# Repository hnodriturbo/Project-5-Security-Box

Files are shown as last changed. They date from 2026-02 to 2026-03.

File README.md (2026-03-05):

# Project 5 – 3D Printed Security Drawer Box

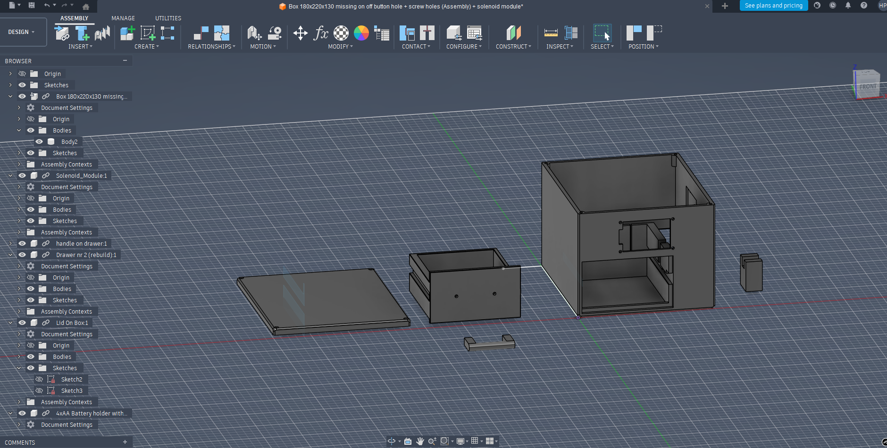
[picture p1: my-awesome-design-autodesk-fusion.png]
Fusion Design


---

## Latest update = VIDEO USAGE:

https://github.com/hnodriturbo/Project-5-Security-Box/raw/master/usage_function_video.mp4

NOTE: MAIN CODE IS IN /esp32-s3

---
## 1. Project Overview

3D printed IoT security drawer box built around an ESP32-S3 and Raspberry Pi running NiceGUI.

### Unlock Methods
- RFID authentication  
- Remote MQTT unlock from dashboard  

The system validates real physical drawer movement using a reed switch and reports whether the unlock was confirmed or failed.

This project demonstrates:

- IoT communication using MQTT  
- JSON-based data exchange  
- Real actuator control (solenoid)  
- Physical validation using reed switch  
- Mechanical precision 3D design  

---

## 2. System Architecture

ESP32 ↔ MQTT Broker ↔ Raspberry Pi (NiceGUI)

### ESP32
- Handles RFID authentication  
- Controls solenoid via TB6612FNG  
- Reads reed switch state  
- Drives OLED display  
- Controls LED strip  
- Sends heartbeat and status data  

### Raspberry Pi
- Hosts NiceGUI dashboard  
- Sends remote unlock command  
- Displays system status  
- Logs events  

---

## 3. Flow Chart

<p align="center">
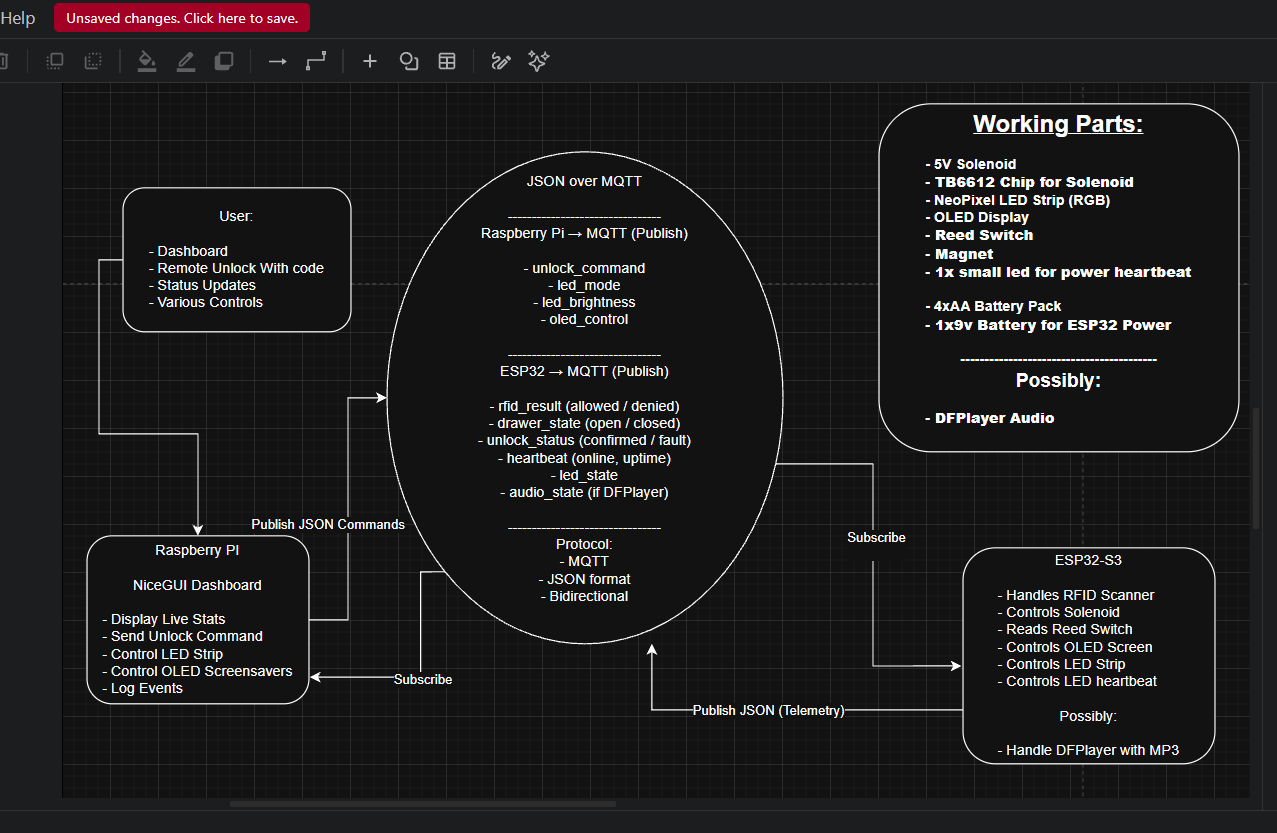
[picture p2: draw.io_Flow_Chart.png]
  
</p>

The system flow chart was created in draw.io and illustrates:

- Authentication logic  
- Unlock decision flow  
- Reed confirmation  
- Fault handling  
- Reset logic  

---

## 4. Hardware

- ESP32-S3  
- TB6612FNG motor driver  
- 5V solenoid lock  
- Reed switch + magnet  
- MFRC522 RFID reader  
- 2.42" OLED (SSD1309 SPI)  
- NeoPixel LED strip (GRB)  
- 9V battery (logic power)  
- 4xAA battery pack (solenoid power)  
- Raspberry Pi  

---

## 5. MQTT & IoT Protocol

Communication protocol used:

- MQTT  
- JSON  

Broker will be used using mosquitto and Raspberry Pi system using the school network
- Known broker IP: `10.201.48.7` (could be something else next time it powers on)

All communication between ESP32 and Raspberry Pi is handled using structured JSON messages over MQTT.

Detailed message formats will be documented separately in the project documentation.

---

## 6. Software

### ESP32

Programmed in **MicroPython**.  
Handles hardware interaction, MQTT communication, state management, and feedback systems.

### Raspberry Pi

Runs **NiceGUI (Python)**.  
Provides dashboard interface, remote control functionality, and live monitoring.

---

## 7. CAD & Mechanical Design

Folder: `cad/`

Designed in Autodesk Fusion.

Contains STL exports for:

- **Main Box Design**
- **Sliding Drawer Design**
- **Sliding Drawer Handle Design**
- **Solenoid Mounting Structure Design**
- **Spring Holders Design**

The design focuses heavily on mechanical precision due to the solenoid having approximately 2mm of usable locking depth.

---

## 8. Known Limitations

- Battery powered demo build  
- High LED + solenoid load may cause voltage drop  
- Mechanical tolerances will be fully validated after final print  

---

## 9. Future Improvements

- DFPlayer Mini + speaker for audio feedback  
- Internal voltage regulation  
- Improved drawer alignment refinement ✅ 
- Local MQTT broker on Raspberry Pi ✅ 

---

## 10. Project Coverage

This project fulfills:

- Telemetry  
- Actuator control  
- Raspberry Pi + NiceGUI integration  
- Full IoT physical prototype design  
- 3D printed mechanical system

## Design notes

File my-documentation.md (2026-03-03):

# Documentation of Creation of the Security Box

This document logs the development process of the 3D Printed IoT Security Drawer Box.  
It describes design decisions, challenges, mechanical iterations, and open questions during development.

---

## 15–22 Feb — Mechanical Design Phase (Autodesk Fusion)

During this period I focused heavily on the mechanical design of the box in Autodesk Fusion.  
This phase required significant precision because the solenoid locking mechanism only has approximately **2mm of usable locking pin depth**, which leaves very little room for error.

--- 

## 26 Feb - Box printing failed, but drawer and solenoid stand + handle on drawer printed

I will have the box late or on Monday, 2 days before assignment completion so i have started working on the codings, having everything connected together at home illustrating the box design. This is a complex coding system that I'm designing so for ease of commanding everything I created a class file for every component that will be used, so instances can call easily on premade functions within those instance related classes.

PROBLEM: I thought the pin would have more power but 4xAA is not giving the pin the power to pull in when pressure is on it. Even just a tiny bit of pressure so the spring system will be withdrawed from the design and unlocking will unlock for 5 seconds and user has to manually open the drawer but otherwise it's locked into place by the solenoid. I would need more power then 4xAA batteries for making the pin pull in with force or this is just so basic and small solenoid that I must redesign this. It was not the main purpose but I will have to acumulate to these conditions and create new TRUE PURPOSE of the box by having the user having to open the drawer manually when presented with phone, card, keychain or command from dashboard. I will focus more on the engine design, the lightings and more to make up for this and create fully functional dashboard with NiceGUI that can make many different commands to the box, change screen main texts, change lighting scenes, unlock with a code (code only unlock from dashboard for "security") and more features will also be available in the dashboard.

---

## 27-28 Feb & 1-3 Mar — Printing Issues & Coding Phase

After the first full box print, I immediately ran into mechanical issues. The bottom surface of the box printed uneven, which affected structural alignment and drawer seating. Because of this, the drawer did not fit correctly. I had to manually adjust and widen certain areas using tools just to make it fit temporarily inside the faulty print. This obviously changed tolerances and is not acceptable for final assembly.

As a result:

- The full box is being reprinted and I am currently waiting for the new version.
- The drawer also needs to be reprinted to restore its true dimensions.
- These corrected parts will be ready tomorrow, on the day of the deadline.
- Final mechanical construction and full assembly will happen immediately once the prints are ready.

Because I did not want to lose time while waiting for the reprint, I shifted focus entirely to the coding phase.

---

## ESP32 Software Architecture Development

While waiting for the new box print, I built and structured the entire ESP32 system from scratch. This part was significantly more complex than expected.

The main difficulty was not hardware — it was architecture.

I wanted:

- Separate class files for every hardware component  
- Clean separation between logic, hardware, and MQTT communication  
- Two independent MQTT pathways (receive and transmit)  
- Structured JSON communication  
- No dynamic guessing or unsafe method calls  
- Beginner-readable but structured code  

This caused several major debugging cycles.

Problems I faced during development:

- MQTT client queue handling errors  
- Async task crashes not being retrieved properly  
- Reconnect loops failing silently  
- JSON parsing issues  
- Multiple overlapping log functions that needed to be merged  
- OLED display not updating because async calls were blocked  
- Unlock flow timers interfering with display logic  
- RFID scan loop not running due to incorrect task structure  
- ESP disconnecting after publish attempts  
- Attribute errors due to inconsistent broker methods  

The system had to be redesigned more than once to make it clean and understandable.

Eventually, I simplified everything into:

- A central `SecurityBoxController`  
- Explicit `CommandRouter`  
- One unified logging system  
- Minimal JSON messages  
- Two MQTT topics:  
  - Subscribe: `1404TOPIC/Commands`  
  - Publish: `1404TOPIC/Events`  
- Clear async task separation  
- Component classes that only do their own job  

After many iterations and structural changes, the ESP32 code is now stable and behaves as expected. HOPEFULLY!

---

## NiceGUI Dashboard & Broker Setup

While developing the ESP32 code, I also completed the NiceGUI dashboard.

I am using my own MQTT broker setup at home.  
Connection between:

ESP32 ↔ Broker ↔ NiceGUI

is working properly.

The dashboard can:

- Send unlock commands  
- Trigger LED effects  
- Change OLED screen text  
- Display structured events from the ESP  
- Log events with timestamps  
- Handle connection and reconnection states  

After a large number of debugging cycles and communication fixes, the full ESP ↔ MQTT ↔ NiceGUI communication loop is functioning correctly.

---

## Current Status Before Final Assembly

At this point:

- Solenoid works electrically - NOTE: SOMETIMES I NEED TO MOVE WIRES OR KNOCK ON THE SOLENOID FOR IT TO WORK - POSSIBLE HUGE PROBLEM !!!
- MQTT communication is verified  
- NiceGUI dashboard is fully operational  
- All component classes are structured and separated  
- LED strip effects and unlock flow logic completed  
  
- Reed switch should block everything that's going on and display on screen DRAWER OPEN until the magnet on the drawer connects the reed switch (then unlock the screen and loop)
- ESP32 code is stable except for reed sensor testing that is hard to do when not with the printed box and magnet glued on the drawer

Remaining steps:

- Receive corrected box and drawer print  
- Assemble full hardware  
- Mount electronics  
- Perform final mechanical alignment  
- Validate full unlock + drawer interaction  
- Record final test results  
  
Despite multiple mechanical and coding setbacks, the system is now logically complete and ready for final physical integration. (without reed sensor)

---

# Project information !!!

### CAD Tool Decision

I chose Autodesk Fusion because it provides:

- Parametric modeling
- Precise dimensional control
- Better constraint handling
- Timeline-based modification for iterative design

This project requires millimeter-level precision, especially around:
- Solenoid placement
- Drawer rail tolerances
- Reed switch alignment
- Magnet positioning

---

### Solenoid Mount Strategy

One important architectural decision was to design the solenoid stand as a **separate modular component** that will be glued into place.

Reasoning:

- If tolerances are slightly off after printing, I can reprint only the solenoid mount.
- Avoids reprinting the entire box structure.
- Allows micro-adjustments if the 2mm locking engagement needs repositioning
  
### Solenoid update 3.3.2026
- After positioning solenoid in the solenoid 3d printed stand it is exactly like it's supposed to be and fits perfectly even with its 1.7mm locking space inside the side of the drawer. Only check left is to see if it will open when springs on drawer will put light pressure on it (must have full battery power for stronger solenoid signal).
---

### Drawer & Internal Structure Challenges

Designing the internal structure took significantly more time than expected.

Key challenge:
Creating a space behind the inner drawer wall for:
- Springs
- Reed switch
- Magnet alignment

Final decision:
- **10mm gap** between drawer back wall and inner back wall.
- Magnet glued to rear of drawer.
- Reed switch mounted on internal wall.
- On closed position → magnet activates reed sensor.
- Solenoid engages locking pocket.

Because of spring pressure pushing the drawer forward, this entire system requires:
- Precise rail guidance
- Minimal side wobble
- Controlled alignment at locking point

To achieve this I:

- Increased wall thickness to **5mm standard**
- Added structural rails
- Designed inner reinforcement walls
- Added a mechanical stopper feature at the front so the drawer seats fully before rail alignment takes over

---

### Rail & Tolerance Adjustments

Several iterations were made regarding:

- Side clearances (0.3–0.6 mm precision clearences?)
- Vertical rail spacing
- Rail width (4mm → considered 5mm)
- Friction concerns with solenoid side-contact

Because the solenoid does not have a latch hook, friction against its body was a major design constraint.  
A slide geometry was introduced to gently push the solenoid inward ~1mm before it drops into the locking pocket.

The locking pocket itself was extended upward to allow manual widening with tools if necessary after printing.

---

### Front Panel & Electronics Mounting

Additional design work completed:

- Screw holes (4mm diameter, 10mm depth planned)
- Reinforced lid screw zones (extra material added)
- Inward extrudes for PCB mounting (OLED + RFID)
- Relief cut for OLED header pins
- Circular opening for RFID antenna to improve signal reliability

Special attention was given to:
- Avoiding stress concentration at corners
- Ensuring enough material thickness behind PCB mount areas
- Making sure drawer removal remains possible

---

### Power & Structural Considerations

Power design:
- 9V battery for ESP32 logic rail
- 4xAA battery pack for solenoid
- Shared ground

Concerns:
- Solenoid draws ~1A+
- LED strip can draw multiple amps at full white
- Risk of ESP brownout under heavy load

Structural reinforcement was added where necessary to reduce flex around locking area.

---

### Open Questions (To Be Answered After First Print)

The following mechanical uncertainties cannot be confirmed until physical testing:

- Will the 2mm solenoid locking depth reliably hold the drawer while springs push forward?

- When spring force is applied to the locking pin, will the solenoid release smoothly or bind due to lateral pressure?
  -  TRUE - Solenoid cannot open when even the slightest pressure is on it. I have no time to reprint new design to make the locking in a different way structurally. But would if i had more // 🕗 

- Will rail tolerances provide smooth sliding without wobble?

- Will the drawer self-align perfectly into the rails and locking pin lock the drawer?

- Will friction over time wear down the locking edge?
  - No it will not since this is only a part project that will be taken apart when finished.

These will only be confirmed during:
- First full assembly
- Solenoid activation testing
- MQTT + unlock validation phase

---

- Testing & Performance Results:
  - Testing the solenoid with all connected parts (not inside the box) seems good. Only problem is we need to exclude the springs because the solenoid will not open when friction is pushing on it by the springs pushing the drawer outwards.
  - SOLENOID DOESNT ALWAYS OPEN !!! NOTE: COULD BE FATAL TO PROJECT FUTURE AVAILABILITY BUT FOR NOW IT WORKS IN BETWEEN WHEN USING BRAND NEW BATTERIES.

---

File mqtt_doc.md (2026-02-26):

# MQTT Architecture Documentation  
Project 5 – 3D Printed Security Drawer Box  

---

# 1. Overview

This system uses a local MQTT broker running on the Raspberry Pi to connect:

- ESP32-S3 (MicroPython device inside the box)  
- NiceGUI dashboard (running on Raspberry Pi)  
- Mosquitto broker (running on Raspberry Pi)  

The broker acts as a message router between ESP32 and NiceGUI.

There is no direct communication between ESP32 and NiceGUI.  
All communication flows through MQTT.

---

# 2. System Architecture

## ESP32-S3

- RFID reader (MFRC522)  
- Reed switch (drawer state)  
- Solenoid (TB6612FNG driver)  
- OLED display  
- NeoPixel LED strip (GRB)  
- DFPlayer audio  
- MQTT client (MicroPython)

## Raspberry Pi

- Mosquitto MQTT Broker (port 1883)  
- NiceGUI Dashboard (Python application)  
- MQTT client inside NiceGUI  

---

# 3. Network Structure

## MQTT Broker

Runs locally on Raspberry Pi:

`Mosquitto`  
`Port: 1883`  
`Listener: 0.0.0.0`  
`Anonymous: true (demo mode)`

BROKER IP !!!!
`10.201.48.7`

## Connection Targets

| Device | Broker Address |
| --- | --- |
| NiceGUI  | `127.0.0.1` |
| ESP32-S3 | `10.201.48.77` |

---

# 4. Communication Flow

ESP32 publishes telemetry → Broker → NiceGUI receives  
NiceGUI publishes commands → Broker → ESP32 receives  

The broker is the central router.

---

# 5. Topic Structure

Base namespace:

`security_box/`

## 5.1 Telemetry (ESP32 → Pi)

`security_box/telemetry/heartbeat`  
`security_box/telemetry/drawer_state`  
`security_box/telemetry/system_status`

## 5.2 Events (ESP32 → Pi)

`security_box/event/rfid`  
`security_box/event/unlock_result`  
`security_box/event/fault`

## 5.3 Commands (Pi → ESP32)

`security_box/cmd/unlock`  
`security_box/cmd/led`   
`security_box/cmd/oled`

---

# 6. Unlock Flow Example

1. RFID scanned on ESP32  
2. ESP32 checks allowed UID  
3. If allowed:  
   - Activate solenoid  
   - Wait for reed switch change  
   - Publish `security_box/event/unlock_result`  
4. NiceGUI receives and logs result  

Remote unlock works similarly:

1. NiceGUI publishes to `security_box/cmd/unlock`  
2. ESP32 activates solenoid  
3. Reed switch validates open  
4. ESP32 publishes unlock result  

---

# 7. Summary

Raspberry Pi runs:

- Mosquitto (MQTT message router)  
- NiceGUI dashboard  

ESP32 runs:

- Hardware control logic  
- MQTT client  

All communication is JSON over MQTT using a structured namespace.

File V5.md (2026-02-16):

# Tímaverkefni 5 

- IoT frumgerð 
- Námsmat 32% af heildareinkunn  

---

## Verkefnalýsing

Lokaverkefnið snýr að IoT frumgerðasmíð. Viðfangefni og útfærsla er frjáls en er **háð samþykki kennara** og þarf að uppfylla ákveðna verkþætti (sjá neðar). Verkefnið þarf að vera ykkar eigið og gert er ráð fyrir **sjálfstæðum** vinnubrögðum. Skoðið [Adafruit](https://learn.adafruit.com/category/internet-of-things-iot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) og [Hackster](https://www.hackster.io/iot/projects) fyrir innblástur og hugmyndir. 

#### Verkþættir sem þarf að uppfylla:

- [ ] Telemetry: Unnið er með inntak frá völdum skynjurum, sjá [lista af íhlutum](https://github.com/VESM3/IOT/blob/main/Ihlutir.md).
- [ ] Actuators: Unnið er með valdar stýringar, sjá [lista af íhlutum](https://github.com/VESM3/IOT/blob/main/Ihlutir.md).
- [ ] MQTT Broker uppsetning, [leiðbeiningar](https://github.com/VESM3/IOT/blob/main/Efni/rpi_mqtt_nodered_uppsetning.md#mosquitto-mqtt-broker).
- [ ] NiceGUI: Mælaborði fyrir birtingu gagna og notendastýringar.
- [ ] IoT Protocol: MQTT. 
- [ ] JSON fyrir gögn.
- [ ] [Flæðirit](https://www.drawio.com/doc/getting-started-basic-flow-chart) (e. flow chart) af IoT Frumgerð.
- [ ] Samsettning á IoT búnaði (innfelld kerfi, íhlutir, brauðbretti, vírar osfrv.).
- [ ] Smíði IoT frumgerðar (3D prentað, 2D laserskornir, veróborðsmíði, lóðun, samsettning og útlit).
- [ ] Skýrsla á Github (readme.md).

---

### Skýrsla og skil

Búið til private Github geymslu (repository) og skrifið skýrslu ([leiðbeiningar](https://github.com/VESM1VS/AFANGI/blob/main/Kennsluefni/skyrslugerd.md)) í `readme.md` sem innheldur eftirfarandi: 

1. Stutt textalýsing á IoT frumgerð og virkni.
1. Stutt myndband af virkni. 
1. Ljósmyndir af IoT frumgerð.
1. Íhlutalisti, allir íhlutir sem notaðir eru í verkefninu.
1. Flæðirit (e. flow chart) af IoT Frumgerð.
1. Hönnunarteikningar (til prentunar) 2d (svg) og 3d teikningar (.stl skráin).
1. Tenglar á kóðaskrár vel commentað.

Skilið í Innu tengil á skýrsluna (`readme.md`). Skil á skýrslu er forsenda þess að gefin sé einkunn fyrir verkefnið. Hugið vel að uppsetningu og framsetningu! Vinsamlegast gerið einnig eftirfarandi í Innu: [Samþykki fyrir birtingu verkefnis á vef](https://github.com/VESM3/IOT/blob/main/Verkefni/samthykki.md) 

---

### Námsmat 

Einkunn byggir á útfærslum á eftirfarandi matsþáttum og vinnuframlagi sem á sér stað í kennslustund.

#### Matsþættir:

1. Inntak (telemetry)  **(25%)**
   1. Forritun, MQTT, JSON.
   1. Skynjarar og tengingar í IoT búnaði.
1. Stýringar (actuator)  **(25%)**
   1. Forritun, MQTT, JSON.
   1. Stýringar og tengingar í IoT búnaði.
1. Raspberry Pi **(25%)** 
   1. NiceGUI, mælaborð fyrir birtingu gagna og notendastýringu.
   1. MQTT Broker.
1. IoT Frumgerð **(25%)**
   1. Samhæfing og virkni IoT frumgerðar.
   2. Hönnun, smíði og útlit IoT frumgerðar.

#### Matskvarði fyrir hvern matsþátt: 

- 10 Framúrskarandi útfærsla og frágangur. 
- 7.5 Góð lausn en smávægilega ábótavant. 
- 5 Lausn er hálfnuð eða vantar mikilvæga þætti. 
- 2.5 lausn er stórlega ábótavant.
- 0 Óunnið eða vantar.

> [!Note]
> - Fyrir hverja kennslulotu (4 x 50 mín) í skóla sem nemandi mætir **ekki** dregst **1** frá einkunn hjá viðkomandi. <br>
> - Það er ekki í boði að nota gervigreind til að vinna kóðann fyrir þig! <br>
> - Passaðu að þú getir útskýrt kóðann sem þú skilar fyrir kennara. Getir þú ekki útskýrt kóða verður gefið 0 (núll) fyrir matsþátt.

<!--
- lokaverkefni nemenda: https://github.com/Verksmidja
- https://github.com/VESM3/IOT/blob/main/IoTVerkefni_Hugmyndir.md
- https://hackaday.com/tag/mqtt/
- https://circuitdigest.com/internet-of-things-iot-projects
- https://maker.pro/projects/category/iot?filter=popular
-->

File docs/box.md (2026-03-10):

# ESP32-S3 Security Box — Code Documentation

This document explains how the ESP32 code works, file by file.

---

## File Overview

| File | Role |
| --- | --- |
| `main.py` | Boot sequence, creates hardware, wires callbacks |
| `box_procedures.py` | System logic, event handlers, command router |
| `mqtt_json_broker.py` | WiFi + MQTT connection lifecycle |
| `class_files/oled_screen.py` | SSD1306 display driver |
| `class_files/led_strip.py` | WS2812 NeoPixel controller |
| `class_files/solenoid_lock.py` | TB6612 motor driver for latch |
| `class_files/reed_switch.py` | Drawer open/close detection |
| `class_files/rfid_scanner.py`  | MFRC522 card reader |

---

## Boot Order (main.py)

The box boots in a strict order so each component can show its status on the OLED:

```
1. OledScreen   → display ready first (shows boot messages for all others)
2. LedStrip     → "LED STRIP / STARTED / OK" + idle loop starts
3. Solenoid     → "SOLENOID / STARTED / OK" (initialized locked)
4. ReedSwitch   → "REED SWITCH / STARTED / OPEN|CLOSED"
5. RFID         → created but NOT started (waits for MQTT)
6. MqttJsonBroker → connects WiFi + MQTT, shows status
7. Procedures   → wires reed callbacks, receives broker + RFID hooks
8. rfid.start() → now safe to scan cards
9. show_main_mode() → idle screen shown
```

After boot, `while True: await asyncio.sleep_ms(250)` keeps the event loop alive.

---

## box_procedures.py

**Role:** The brain of the system. Receives events from RFID, reed switch, and MQTT. Decides what to do.

### Key State Flags

| Flag | Purpose |
| --- | --- |
| `unlock_in_progress` | True during unlock countdown |
| `system_locked` | True = drop all RFID scans and commands |
| `drawer_is_open` | True when reed detects open drawer |

### Helper Methods

| Method | What it does |
| --- | --- |
| `get_timestamp()` | Returns ISO-ish timestamp from RTC |
| `publish(payload)` | Sends dict to MQTT (silent drop if offline) |
| `notify(line1, line2, line3, event, **extra)` | Console + OLED + optional MQTT event |
| `ack(command, status, **extra)` | Sends `command_ack` event back to dashboard |
| `oled_show_then_restore()` | Async: show text, wait, return to idle |

### Reed Callbacks

| Callback | Trigger | Actions |
| --- | --- | --- |
| `on_drawer_open()`  | Drawer physically opened | Solenoid off, show "DRAWER OPEN", publish `drawer_opened` |
| `on_drawer_close()` | Drawer physically closed | Solenoid off, publish `drawer_closed`, return to idle |

### RFID Callbacks

| Callback | Trigger | Actions |
| --- | --- | --- |
| `on_rfid_allowed(payload)` | Whitelisted card scanned | Starts `unlock_procedure_async` |
| `on_rfid_denied(payload)`  | Unknown card scanned | Show "DENIED", blink red, publish `rfid_denied` |

### Unlock Procedure Steps

```
1. Guard check (already unlocking?)
2. Set system_locked = True
3. Show "ACCESS GRANTED" for 2s
4. Blink green async
5. Publish access_allowed event
6. Energize solenoid
7. 5-second countdown (break early if drawer opens)
8. De-energize solenoid
9. Branch:
   - Drawer opened → publish drawer_opened_during_unlock
   - Not opened → show "WINDOW ENDED", tail animation, publish unlock_window_ended
10. Reset flags, return to idle
```

### Command Handler

`handle_command(msg)` routes incoming JSON from dashboard:

| Command | Action |
| --- | --- |
| `unlock` | Start unlock procedure (source="remote") |
| `led_idle_on` | Enable LED screensaver |
| `led_idle_off` | Disable LED screensaver |
| `led_blink` | Blink with custom RGB + times |
| `led_idle_1` | Switch to idle animation mode 1 |
| `led_idle_2` | Switch to idle animation mode 2 |
| `led_tail` | Run tail animation with color/cycles/speed |
| `led_off` | Turn strip completely off |
| `set_idle_screen` | Change OLED idle text |
| `oled_show` | Show custom text for hold_ms |

---

## mqtt_json_broker.py

**Role:** Owns WiFi and MQTT connection. Reconnects forever on failure.

### Connection Strategy

1. Try primary WiFi → if fail, try fallback WiFi
2. Try primary broker → if fail, try fallback broker
3. If both brokers fail: `broker_unreachable = True`, retry in background
4. If no WiFi found: `offline = True`, retry in 30s

### Topics

| Topic | Direction |
| --- | --- |
| `MyTopic/Commands` | Subscribe (receive from dashboard) |
| `MyTopic/Events` | Publish (send to dashboard) |

### Key Methods

| Method | Purpose |
| --- | --- |
| `start(oled)` | Launch `run_forever()` as background task |
| `wait_ready()` | Blocks until connected OR offline confirmed |
| `send_json(dict)`  | Publish dict as JSON to Events topic |
| `set_callback(fn)` | Wire command handler |

### Receive Loop

Polls `client.check_msg()` every 30ms. When message arrives:
1. Decode JSON
2. Call `command_callback(payload)` → `procedures.handle_command()`

---

## Hardware Classes

### oled_screen.py

- **Driver:** SSD1306_SPI over SPI bus
- **Resolution:** 128×64 pixels
- **Main method:** `show_three_lines(line1, line2, line3)` — clears screen, draws 3 centered lines
- **Idle screen:** `set_idle_screen((l1, l2, l3))` stores text, `show_main_mode()` displays it
- **Async hold:** `log_now(l1, l2, l3, hold_ms)` — shows text and pauses caller

### led_strip.py

- **Driver:** NeoPixel on GPIO14
- **Count:** 50 LEDs
- **Brightness cap:** 35% max (USB power safety)

**Idle Loop System:**
- `start_idle_loop()` → launch animation task
- `stop_idle_loop()` → cancel + turn off
- `pause_idle_loop_utility()` → cancel task, keep enabled flag
- `resume_idle_loop_utility()` → restart if still enabled

**Two idle animations:**
- Mode 1: Shifting dots, single hue per frame
- Mode 2: Even/odd alternating, full rainbow

**Effects:**
- `blink_color_async(r, g, b, times)` — auto-pauses idle, blinks, resumes
- `tail_circular_async(cycles, delay_ms, r, g, b)` — chasing tail

### solenoid_lock.py

- **Driver:** TB6612FNG motor driver (A-channel)
- **GPIO:** AIN1 on pin 12
- **`on()`** → energize coil (release latch)
- **`off()`** → de-energize (lock)

### reed_switch.py

- **GPIO:** Pin 16 with pull-up
- **Logic:** LOW = closed (magnet near), HIGH = open
- **Debounce:** 1 second stable before callback fires
- **Background task:** `poll_loop()` runs forever, fires `on_open` / `on_close`

### rfid_scanner.py

- **Driver:** MFRC522 over SoftSPI
- **Whitelist:** Dict mapping UID hex → label
- **Prefix match:** `["08"]` for phones
- **Scan loop:** Runs in background, fires `on_allowed` / `on_denied`

---

## JSON Events (ESP32 → Dashboard)

| Event | Trigger | Key Fields |
| --- | --- | --- |
| `access_allowed` | Card accepted | `source`, `label`, `uid_suffix`, `timestamp` |
| `rfid_denied` | Card rejected | `source`, `data.uid_suffix`, `timestamp` |
| `drawer_opened` | Reed detects open | `timestamp` |
| `drawer_closed` | Reed detects close | `status`, `timestamp` |
| `drawer_opened_during_unlock` | Drawer opened during countdown | `source`, `timestamp` |
| `unlock_window_ended` | Countdown expired, drawer not opened | `source`, `timestamp` |
| `command_ack` | Command processed | `command`, `status`, `timestamp` |
| `heartbeat` | Every 60s | `uptime_s`, `drawer`, `locked`, `timestamp`  |

---

## JSON Commands (Dashboard → ESP32)

| Command | Parameters |
| --- | --- |
| `unlock` | none |
| `led_idle_on` | none |
| `led_idle_off` | none |
| `led_off` | none |
| `led_idle_1` | none |
| `led_idle_2` | none |
| `led_blink` | `r`, `g`, `b`, `times` |
| `led_tail` | `r`, `g`, `b`, `cycles`, `delay_ms`  |
| `set_idle_screen` | `line1`, `line2`, `line3` |
| `oled_show` | `line1`, `line2`, `line3`, `hold_ms` |

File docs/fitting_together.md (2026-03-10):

# Fitting Together — ESP32 + NiceGUI Communication

This document explains how the ESP32 and Dashboard work together.

---

## Architecture Overview

```
┌──────────────────────────────────────────────────────────────────┐
│                      Mosquitto Broker                            │
│                   (on Raspberry Pi or Home Server)               │
│                                                                  │
│   MyTopic/Commands ◄──────────────── MyTopic/Events ◄─────────  │
│         │                                   ▲                    │
│         ▼                                   │                    │
│   ┌─────────────┐                   ┌───────┴───────┐            │
│   │   ESP32     │                   │   Dashboard   │            │
│   │ subscribes  │                   │   subscribes  │            │
│   └─────────────┘                   └───────────────┘            │
└──────────────────────────────────────────────────────────────────┘
```

**Bi-directional flow:**
- **Dashboard → ESP32:** Commands via `MyTopic/Commands`
- **ESP32 → Dashboard:** Events via `MyTopic/Events`

---

## Connection Sequence

### ESP32 Side

```
1. main.py boots all hardware
2. MqttJsonBroker.start() launches run_forever() task
3. Try primary WiFi (TskoliVESM), fallback (Hringdu-jSy6)
4. Try primary broker (10.201.48.7), fallback (192.168.1.51)
5. Subscribe to MyTopic/Commands
6. receive_loop() polls check_msg() every 30ms
7. On disconnect, reconnect forever
```

### Dashboard Side

```
1. on_startup() calls mqtt.start_mqtt_thread()
2. Separate thread with SelectorEventLoop
3. Try BROKER_PRIMARY, then BROKER_FALLBACK
4. Subscribe to MyTopic/Events
5. mqtt_receive_loop() reads messages via async for
6. mqtt_publish_loop() drains publish_queue, sends to Commands
7. On disconnect, reconnect forever
```

---

## Message Flow Examples

### Example 1: Card Scan (RFID → Dashboard)

```
[ESP32 RFID scanner detects card]
        │
        ▼
[on_rfid_allowed() called]
        │
        ▼
[unlock_procedure_async() starts]
        │
        ▼
[publish() sends JSON to MyTopic/Events]
        │
        ▼
    ┌───────────────────────────────────────┐
    │ {"event": "access_allowed",           │
    │  "source": "rfid",                    │
    │  "label": "card",                     │
    │  "uid_suffix": "FC2984",              │
    │  "timestamp": "2026-03-09 17:56:15"}  │
    └───────────────────────────────────────┘
        │
        ▼
[Dashboard mqtt_receive_loop() receives]
        │
        ▼
[handle_inbound() updates state["last_rfid"]]
        │
        ▼
[ui.timer refreshes Last RFID label]
```

### Example 2: Remote Unlock (Dashboard → ESP32)

```
[Operator clicks UNLOCK DRAWER button]
        │
        ▼
[publish_queue.put_nowait({"command": "unlock"})]
        │
        ▼
[mqtt_publish_loop() drains queue]
        │
        ▼
[Publishes to MyTopic/Commands]
        │
        ▼
    ┌───────────────────────────────────────┐
    │ {"command": "unlock"}                 │
    └───────────────────────────────────────┘
        │
        ▼
[ESP32 receive_loop() → on_message()]
        │
        ▼
[procedures.handle_command({"command": "unlock"})]
        │
        ▼
[unlock_procedure_async(source="remote", label="REMOTE")]
        │
        ▼
[ESP32 publishes access_allowed event back]
```

### Example 3: LED Control (Dashboard → ESP32)

```
[Operator sets R=255, G=0, B=0, times=5]
[Clicks "Blink" button]
        │
        ▼
    ┌───────────────────────────────────────┐
    │ {"command": "led_blink",              │
    │  "r": 255, "g": 0, "b": 0,            │
    │  "times": 5}                          │
    └───────────────────────────────────────┘
        │
        ▼
[ESP32 handle_command() matches "led_blink"]
        │
        ▼
[asyncio.create_task(led.blink_color_async(255, 0, 0, times=5))]
        │
        ▼
[ack("led_blink") sends command_ack back]
```

---

## JSON Structure Comparison

### Current ESP32 → Dashboard Events

| Event | Structure |
| --- | --- |
| `access_allowed` | `{event, source, label, uid_suffix, timestamp}` |
| `rfid_denied` | `{event, source, status, data: {uid_suffix}, timestamp}` |
| `drawer_opened`  | `{event, timestamp}` |
| `drawer_closed`  | `{event, status, timestamp}` |
| `command_ack` | `{event, command, status, timestamp}` |
| `heartbeat` | `{event, uptime_s, drawer, locked, timestamp}` |

### Current Dashboard → ESP32 Commands

| Command | Structure |
| --- | --- |
| `unlock` | `{command}` |
| `led_blink` | `{command, r, g, b, times}` |
| `led_tail` | `{command, r, g, b, cycles, delay_ms}` |
| `set_idle_screen` | `{command, line1, line2, line3}` |
| `oled_show` | `{command, line1, line2, line3, hold_ms}` |

---

## State Synchronization

### What Dashboard Knows

| State | Source | How Updated |
| --- | --- | --- |
| MQTT connected | `state["mqtt_connected"]` | Set in receive loop on connect/disconnect |
| Last RFID | `state["last_rfid"]` | Updated by `handle_inbound()` on access events |
| Last event | `state["last_event"]` | Raw payload of most recent event |
| Event log | `log_lines[]` | `add_log()` on every significant event |

### What ESP32 Knows

| State | Source | How Updated |
| --- | --- | --- |
| Drawer state | `reed.is_open` | Reed switch poll loop |
| Unlock in progress | `procedures.unlock_in_progress` | Set/cleared by unlock procedure |
| System locked | `procedures.system_locked` | Set during procedures |
| MQTT connected | `broker.connected` | Set in connection loop |

---

## Offline Behavior

### ESP32 Without Broker

```
1. WiFi connects
2. Both brokers unreachable
3. broker_unreachable = True
4. main.py continues to rfid.start()
5. RFID scanning works locally
6. unlock_procedure_async() runs normally
7. publish() silently drops messages
8. Background retry every 120s
```

### ESP32 Without WiFi

```
1. Neither SSID in range
2. offline = True
3. OLED shows "Net, Broker / Not Available / Scan RFID"
4. System fully functional locally
5. Background retry every 30s
```

### Dashboard Without Broker

```
1. Both brokers unreachable
2. state["mqtt_connected"] = False
3. Badge shows "○ MQTT Offline"
4. Commands queued in publish_queue
5. Retry connection forever
```

---

## Timing Relationships

| Event | Timing |
| --- | --- |
| Dashboard UI refresh | Every 0.5s |
| ESP32 heartbeat | Every 60s |
| ESP32 MQTT poll | Every 30ms |
| Reed switch debounce | 1s stable |
| RFID scan delay | 150ms between reads |
| Unlock countdown | 5 seconds |

---

## Error Handling

### ESP32 Side

| Failure | Response |
| --- | --- |
| WiFi disconnect | `run_forever()` reconnects |
| Broker disconnect | Mark `connected = False`, retry |
| JSON parse error | Log to console, ignore message  |
| Command handler crash | Log error, continue |

### Dashboard Side

| Failure | Response |
| --- | --- |
| Broker disconnect | Mark `mqtt_connected = False`, retry |
| JSON parse error  | Log "Parse error", ignore message |
| Publish fail | Try all brokers, log if all fail |

---

## Adding a New Command (Step by Step)

### 1. Add handler in box_procedures.py

```python
# In handle_command():
elif command == "my_new_command":
    value = msg.get("value", 0)
    # Do something with value
    self.ack("my_new_command")
```

### 2. Add button in dashboard.py

```python
ui.button(
    "My New Command",
    on_click=lambda: mqtt.publish_queue.put_nowait({
        "command": "my_new_command",
        "value": 42,
    }),
)
```

### 3. (Optional) Add event handling in mqtt_handler.py

```python
# In handle_inbound():
elif event == "my_new_event":
    add_log("My new event: {}".format(data))
```

---

## Topic Summary

| Topic | Publisher | Subscriber |
| --- | --- | --- |
| `MyTopic/Commands` | Dashboard | ESP32 |
| `MyTopic/Events` | ESP32 | Dashboard  |

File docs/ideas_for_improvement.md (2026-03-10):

# Ideas for Improvement

This document lists concrete improvement ideas with file/line references and implementation strategies.

---

## 1. Standardize JSON Structure

**Problem:** ESP32 and Dashboard use inconsistent JSON formats.

### Current Inconsistencies

| Issue | ESP32 Example | Dashboard Expects |
| --- | --- | --- |
| Nested vs flat  | `data: {uid_suffix}` in `rfid_denied` | Checks both top-level and `data` |
| Mixed key names | `command` | Also checks `cmd` |
| No type field | Just `event` or `command` | No way to distinguish source |

### Proposed Standard Format

**Events (ESP32 → Dashboard):**
```json
{
  "type": "event",
  "event": "access_allowed",
  "source": "rfid",
  "timestamp": "2026-03-09 17:56:15",
  "data": {
    "uid_suffix": "FC2984",
    "label": "card"
  }
}
```

**Commands (Dashboard → ESP32):**
```json
{
  "type": "command",
  "command": "led_blink",
  "timestamp": "2026-03-09 17:56:15",
  "params": {
    "r": 255,
    "g": 0,
    "b": 0,
    "times": 3
  }
}
```

**Acknowledgements (ESP32 → Dashboard):**
```json
{
  "type": "ack",
  "command": "led_blink",
  "success": true,
  "timestamp": "2026-03-09 17:56:15"
}
```

### Files to Update

| File | Line | Change |
| --- | --- | --- |
| [box_procedures.py](esp32-s3/box_procedures.py#L239-L252) | `publish()` calls  | Wrap in standard format |
| [box_procedures.py](esp32-s3/box_procedures.py#L95-L103)  | `ack()` method | Add `type: "ack"`, `success` |
| [mqtt_handler.py](nicegui/mqtt_handler.py#L93-L130) | `handle_inbound()` | Parse new format |
| [dashboard.py](nicegui/dashboard.py#L237-L265) | Command buttons | Use `params` wrapper |

---

## 2. LED Strip Zone System

**Problem:** LEDs stop and restart during effects because the whole strip is treated as one unit.

### Proposed Solution: Index-Based Zones

Split the 50 LEDs into named zones:

```python
LED_ZONES = {
    "front":  range(0, 12),     # indices 0-11
    "right":  range(12, 25),    # indices 12-24
    "back":   range(25, 38),    # indices 25-37
    "left":   range(38, 50),    # indices 38-49
}
```

### New Zone Methods

```python
def fill_zone(self, zone_name, r, g, b):
    """Fill a specific zone with color."""
    for i in LED_ZONES.get(zone_name, []):
        self.set_pixel_utility(i, r, g, b)
    self.show()

def chase_zone(self, zone_name, r, g, b, delay_ms=50):
    """Chase effect within one zone only."""
    indices = list(LED_ZONES.get(zone_name, []))
    for i in indices:
        self.set_pixel_utility(i, r, g, b)
        self.show()
        await asyncio.sleep_ms(delay_ms)
        self.set_pixel_utility(i, 0, 0, 0)
```

### Zone-Aware Idle Loop

Instead of iterating `range(led_count)`, iterate per zone:

```python
async def zone_chase_idle_async(self):
    """Chase around the box: front → right → back → left."""
    hue = 0
    while True:
        for zone in ["front", "right", "back", "left"]:
            for i in LED_ZONES[zone]:
                self.turn_off()
                r, g, b = self.hsv_to_rgb_utility(hue, 255, 200)
                self.set_pixel_utility(i, r, g, b)
                self.show()
                hue = (hue + 5) % 360
                await asyncio.sleep_ms(30)
```

### File to Update

| File | Line | Change |
| --- | --- | --- |
| [led_strip.py](esp32-s3/class_files/led_strip.py#L51-L74) | After init  | Add `LED_ZONES` dict |
| [led_strip.py](esp32-s3/class_files/led_strip.py#L200-L230) | New methods | Add zone fill/chase  |

---

## 3. Effect Queue System

**Problem:** Multiple effects can crash if started simultaneously.

### Current Behavior

```python
# In handle_command:
elif command == "led_blink":
    asyncio.create_task(self.led.blink_color_async(...))
elif command == "led_tail":
    asyncio.create_task(self.led.tail_circular_async(...))
```

If both are sent quickly, both tasks run and fight over the LEDs.

### Proposed Solution: Single Effect Lock

```python
class LedStrip:
    def __init__(self, ...):
        ...
        self.effect_lock = asyncio.Lock()
        self.current_effect = None

    async def run_effect(self, name, coro):
        """Queue an effect - only one runs at a time."""
        if self.effect_lock.locked():
            print(f"[LED] Dropping {name} - another effect running")
            return False
        
        async with self.effect_lock:
            self.current_effect = name
            self.pause_idle_loop_utility()
            try:
                await coro
            finally:
                self.current_effect = None
                self.resume_idle_loop_utility()
        return True
```

### Usage

```python
# In handle_command:
elif command == "led_blink":
    asyncio.create_task(self.led.run_effect(
        "blink",
        self.led.blink_color_raw_async(r, g, b, times)
    ))
```

### File to Update

| File | Line | Change |
| --- | --- | --- |
| [led_strip.py](esp32-s3/class_files/led_strip.py#L51-L74) | Init | Add `effect_lock` |
| [led_strip.py](esp32-s3/class_files/led_strip.py#L295-L320) | Effects | Wrap in `run_effect()` |

---

## 4. Circular Flow Animation (Your Request)

**Goal:** Smooth continuous chase around all 4 sides.

### Implementation

```python
async def circular_chase_async(self, delay_ms=25, tail_length=5):
    """
    Smooth chase around all zones: front → right → back → left → repeat.
    Uses a fading tail for motion blur effect.
    """
    # Build full path: front(0-11) + right(12-24) + back(25-37) + left(38-49)
    path = list(range(50))
    tail_brightness = [255, 180, 100, 50, 20][:tail_length]
    
    self.pause_idle_loop_utility()
    hue = 0
    head = 0
    
    while self.idle_loop_enabled:  # runs until stop_idle_loop()
        # Clear strip
        for i in range(self.led_count):
            self.pixels[i] = (0, 0, 0)
        
        # Draw tail behind head
        r, g, b = self.hsv_to_rgb_utility(hue, 255, 200)
        for t, brightness in enumerate(tail_brightness):
            pos = (head - t) % len(path)
            idx = path[pos]
            br = brightness / 255
            self.set_pixel_utility(idx, int(r*br), int(g*br), int(b*br))
        
        self.show()
        
        head = (head + 1) % len(path)
        hue = (hue + 2) % 360
        await asyncio.sleep_ms(delay_ms)
    
    self.resume_idle_loop_utility()
```

### Add as Idle Mode 3

```python
def set_idle_loop(self, mode):
    self.idle_loop_mode = mode
    self.pause_idle_loop_utility()
    self.resume_idle_loop_utility()

def resume_idle_loop_utility(self):
    if self.idle_loop_enabled and self.idle_loop_task is None:
        if self.idle_loop_mode == 1:
            loop_method = self.pixel_idle_loop_async
        elif self.idle_loop_mode == 2:
            loop_method = self.pixel_idle_loop_2_async
        elif self.idle_loop_mode == 3:
            loop_method = self.circular_chase_async
        self.idle_loop_task = asyncio.create_task(loop_method())
```

### New Dashboard Button

```python
ui.button(
    "Idle 3 (Chase)",
    on_click=lambda: mqtt.publish_queue.put_nowait({"command": "led_idle_3"}),
)
```

---

## 5. Command Registration System

**Problem:** Adding commands requires editing multiple places.

### Current Flow to Add Command

1. Edit `handle_command()` in `box_procedures.py`
2. Add button in `dashboard.py`
3. Optionally add event handler in `mqtt_handler.py`

### Proposed: Command Registry

```python
# In box_procedures.py
COMMANDS = {}

def register_command(name):
    """Decorator to register a command handler."""
    def decorator(fn):
        COMMANDS[name] = fn
        return fn
    return decorator

class Procedures:
    @register_command("unlock")
    async def cmd_unlock(self, msg):
        await self.unlock_procedure_async(source="remote", label="REMOTE")
    
    @register_command("led_blink")
    async def cmd_led_blink(self, msg):
        r, g, b = msg.get("r", 0), msg.get("g", 0), msg.get("b", 255)
        await self.led.blink_color_async(r, g, b, msg.get("times", 3))
        self.ack("led_blink")

    def handle_command(self, msg):
        cmd = msg.get("command", "")
        handler = COMMANDS.get(cmd)
        if handler:
            asyncio.create_task(handler(self, msg))
        else:
            self.ack("unknown", status="fail", received=cmd)
```

### Benefits

- Self-documenting: `list(COMMANDS.keys())` shows all commands
- Centralized: Command logic lives next to its decorator
- Extensible: Easy to add metadata (help text, required params)

---

## 6. Dashboard Command Builder

**Problem:** Dashboard has hardcoded buttons for each command.

### Proposed: Dynamic Command Panel

Read available commands from a config or discover them:

```python
AVAILABLE_COMMANDS = [
    {"name": "unlock", "label": "Unlock Drawer", "params": []},
    {"name": "led_blink", "label": "Blink", "params": [
        {"name": "r", "type": "int", "min": 0, "max": 255},
        {"name": "g", "type": "int", "min": 0, "max": 255},
        {"name": "b", "type": "int", "min": 0, "max": 255},
        {"name": "times", "type": "int", "min": 1, "max": 10},
    ]},
    ...
]

def build_command_card(cmd):
    with ui.card():
        ui.label(cmd["label"])
        inputs = {}
        for param in cmd["params"]:
            inputs[param["name"]] = ui.number(param["name"], ...)
        
        def send():
            payload = {"command": cmd["name"]}
            payload.update({k: v.value for k, v in inputs.items()})
            mqtt.publish_queue.put_nowait(payload)
        
        ui.button("Send", on_click=send)
```

---

## 7. Better Error Feedback

**Problem:** When commands fail, dashboard doesn't know why.

### Current

ESP32 sends `{"event": "command_refused", "reason": "drawer is open"}` but dashboard doesn't highlight it.

### Proposed

Add toast notifications on error:

```python
# In mqtt_handler.py handle_inbound():
elif event == "command_refused":
    reason = payload.get("reason", "Unknown")
    add_log(f"⚠️ COMMAND REFUSED: {reason}")
    # Dashboard could show a toast here

elif event == "command_ack":
    if payload.get("status") == "fail":
        add_log(f"❌ COMMAND FAILED: {payload.get('command')}")
```

### Dashboard Toast

```python
# In update_ui():
last = mqtt.state.get("last_event", {})
if last.get("event") == "command_refused":
    ui.notify(last.get("reason"), type="warning")
```

---

## 8. Heartbeat Display

**Problem:** Heartbeat events are logged but not surfaced.

### Current

Only appears in log every 60s.

### Proposed

Add a status card showing:
- Uptime
- Drawer state
- Lock state
- Last heartbeat time

```python
with ui.card().classes("..."):
    ui.label("Box Status")
    status_uptime = ui.label("Uptime: --")
    status_drawer = ui.label("Drawer: --")
    status_lock = ui.label("Lock: --")
    status_last_seen = ui.label("Last seen: --")

# In update_ui():
hb = mqtt.state.get("last_heartbeat")
if hb:
    status_uptime.set_text(f"Uptime: {hb['uptime_s']}s")
    status_drawer.set_text(f"Drawer: {hb['drawer']}")
    ...
```

### File to Update

| File | Line | Change |
| --- | --- | --- |
| [mqtt_handler.py](nicegui/mqtt_handler.py#L93-L130) | handle_inbound  | Store heartbeat in state |
| [dashboard.py](nicegui/dashboard.py#L220-L230) | After RFID card | Add status card |

---

## 9. Reconnection Indicators

**Problem:** Dashboard badge shows connected/offline but not "reconnecting".

### Proposed States

| State | Badge Text | Color  |
| --- | --- | --- |
| Connected | ● MQTT Connected  | Green  |
| Reconnecting | ◐ Reconnecting... | Yellow |
| Offline | ○ MQTT Offline | Red |

### Add to state

```python
state = {
    ...
    "connection_state": "disconnected",  # "connected", "reconnecting", "disconnected"
}
```

---

## 10. Config Sync

**Problem:** WiFi credentials and broker IPs are hardcoded in two places.

### Files with Duplicated Config

| Config | ESP32 Location | Dashboard Location |
| --- | --- | --- |
| Broker IPs | [main.py#L87-L90](esp32-s3/main.py#L87-L90) | [config.py#L34-L35](nicegui/config.py#L34-L35) |
| Topics | [main.py#L91](esp32-s3/main.py#L91) | [config.py#L45-L47](nicegui/config.py#L45-L47) |

### Proposed

Create a shared constants file or use environment variables:

```
# .env on both systems
BROKER_PRIMARY=10.201.48.7
BROKER_FALLBACK=192.168.1.51
MQTT_TOPIC=MyTopic
```

---

## Summary: Priority Order

1. **JSON standardization** — Affects all communication
2. **Effect queue system** — Prevents LED crashes
3. **Zone system** — Enables circular flow
4. **Circular chase animation** — Specific request
5. **Command registry** — Makes adding features easier
6. **Error feedback** — Better UX
7. **Heartbeat display** — Surface hidden data
8. **Config sync** — Reduce duplication
9. **Reconnection states** — Clearer connection status
10. **Dynamic command panel** — Future-proofing

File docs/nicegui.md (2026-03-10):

# NiceGUI Dashboard — Code Documentation

This document explains how the dashboard code works, file by file.

---

## File Overview

| File | Role |
| --- | --- |
| `config.py` | Broker addresses, topics, access code, server settings |
| `mqtt_handler.py` | MQTT connection + publish/subscribe loops |
| `dashboard.py` | Web UI built with NiceGUI |

---

## config.py

Central configuration file. All settings in one place.

| Setting | Value | Purpose |
| --- | --- | --- |
| `BROKER_PRIMARY`  | `10.201.48.7` | School Raspberry Pi |
| `BROKER_FALLBACK` | `192.168.1.51` | Home broker |
| `BROKER_PORT` | `1883` | Standard MQTT port |
| `TOPIC_EVENTS` | `MyTopic/Events` | Subscribe (from ESP32) |
| `TOPIC_COMMANDS`  | `MyTopic/Commands` | Publish (to ESP32) |
| `ACCESS_CODE` | `1404` | Dashboard unlock code |
| `NICEGUI_HOST` | `0.0.0.0` | Listen on all interfaces |
| `NICEGUI_PORT` | `8090` | Web server port |
| `MAX_LOG_LINES` | `100` | Event log buffer size |

**Windows fix:** Sets `WindowsSelectorEventLoopPolicy` for aiomqtt compatibility.

---

## mqtt_handler.py

**Role:** Owns MQTT connection in a background thread. Dashboard only reads shared state.

### Shared State

```python
state = {
    "mqtt_connected": False,    # True when subscribed
    "last_rfid": None,          # {result, display, ts}
    "last_event": None,         # Raw last payload
    "active_broker": None,      # Which broker is connected
}

log_lines = []                  # Event log entries
publish_queue = queue.Queue()   # Commands waiting to send
```

### Why a Separate Thread?

NiceGUI runs its own asyncio loop. aiomqtt needs `add_reader`/`add_writer` which only work on `SelectorEventLoop`. Windows defaults to `ProactorEventLoop`. Solution: run MQTT in a dedicated thread with its own `SelectorEventLoop`.

### Two Async Loops

| Loop | Purpose |
| --- | --- |
| `mqtt_receive_loop()` | Subscribe to Events, process incoming JSON |
| `mqtt_publish_loop()` | Drain `publish_queue`, send to Commands topic |

### Connection Flow

```
1. Try BROKER_PRIMARY
2. If fail, try BROKER_FALLBACK
3. If both fail, retry up to MAX_CONNECTION_RETRIES
4. After max retries, reset counter and keep trying forever
5. On success, subscribe to TOPIC_EVENTS
6. Receive messages via async for message in client.messages
```

### handle_inbound(payload)

Routes incoming events from ESP32:

| Event | Action |
| --- | --- |
| `access_allowed` | Update `last_rfid` with label/uid_suffix, log |
| `rfid_denied` | Update `last_rfid` with DENIED status, log |
| `box_online` | Log message |
| `unlock_window_ended` | Log |
| (any other) | Log raw event data |

### Payload Parsing

Checks both top-level and nested `data` dict for `label`/`uid_suffix`:
```python
label = payload.get("label", "") or data.get("label", "")
uid_sfx = payload.get("uid_suffix", "") or data.get("uid_suffix", "")
```

---

## dashboard.py

**Role:** NiceGUI web application. Builds the UI, reads MQTT state, sends commands.

### Startup Flow

```
1. @app.on_startup: mqtt.start_mqtt_thread()
2. Browser visits /
3. @ui.page("/") index() builds the page
4. ui.timer(0.5s) refreshes UI elements
```

### UI Structure

```
┌─────────────────────────────────────────┐
│ Header: "Security Box Dashboard" + Badge│
├─────────────────────────────────────────┤
│ CARD 1: Access Gate                     │
│   - Code input + Unlock/Lock button     │
│   - Controls column (hidden by default) │
├─────────────────────────────────────────┤
│ CARD 2: Last RFID Event                 │
│   - Shows [ALLOWED/DENIED] label @ time │
├─────────────────────────────────────────┤
│ CONTROLS (when unlocked):               │
│   - Drawer Unlock card                  │
│   - LED Strip card                      │
│   - OLED Display card                   │
├─────────────────────────────────────────┤
│ CARD 3: Event Log                       │
│   - Scrollable terminal view            │
└─────────────────────────────────────────┘
```

### Access Gate Logic

```python
def toggle_access():
    if not dashboard_unlocked:
        if code == ACCESS_CODE:
            controls.set_visibility(True)
            toggle_btn.set_text("🔒 Lock Dashboard")
    else:
        controls.set_visibility(False)
        toggle_btn.set_text("Unlock Dashboard")
```

### UI Timer (0.5s interval)

```python
ui.timer(0.5, lambda: (update_ui(), render_log.refresh()))
```

- `update_ui()`: Updates MQTT badge and Last RFID label
- `render_log.refresh()`: Re-renders event log from `mqtt.log_lines`

### Sending Commands

**Rule:** Never publish inline. Always use the queue.

```python
mqtt.publish_queue.put_nowait({"command": "unlock"})
```

The `mqtt_publish_loop()` drains this queue and sends to broker.

### Command Buttons

| Button | JSON Sent |
| --- | --- |
| UNLOCK DRAWER | `{"command": "unlock"}` |
| Screensaver ON  | `{"command": "led_idle_on"}` |
| Screensaver OFF | `{"command": "led_idle_off"}` |
| Strip OFF | `{"command": "led_off"}` |
| Idle 1 | `{"command": "led_idle_1"}` |
| Idle 2 | `{"command": "led_idle_2"}` |
| Blink | `{"command": "led_blink", "r": X, "g": Y, "b": Z, "times": N}` |
| Run Tail | `{"command": "led_tail", "r": X, "g": Y, "b": Z, "cycles": N, "delay_ms": M}` |
| Set Idle Screen | `{"command": "set_idle_screen", "line1": "...", ...}` |
| Send to OLED | `{"command": "oled_show", "line1": "...", "hold_ms": N}` |

### Event Log Rendering

```python
@ui.refreshable
def render_log():
    for line in reversed(mqtt.log_lines):
        if "DENIED" in line:
            css = "text-red-400"
        elif "ALLOWED" in line:
            css = "text-green-400"
        elif "📥 IN:" in line:
            css = "text-blue-400"
        ...
```

Color coding:
- Red: denied, error, fail
- Green: allowed, sent, connected
- Blue: incoming messages
- Yellow: outgoing messages
- White: other

---

## JSON Events Received (ESP32 → Dashboard)

| Event | Key Fields | UI Update |
| --- | --- | --- |
| `access_allowed` | `source`, `label`, `uid_suffix`, `timestamp` | Last RFID label, log |
| `rfid_denied` | `data.uid_suffix`, `timestamp` | Last RFID label (red), log |
| `drawer_opened`  | `timestamp` | Log |
| `drawer_closed`  | `status`, `timestamp` | Log |
| `command_ack` | `command`, `status` | Log |
| `heartbeat` | `uptime_s`, `drawer`, `locked` | Log |

---

## JSON Commands Sent (Dashboard → ESP32)

| Command | Parameters | Purpose |
| --- | --- | --- |
| `unlock` | none | Remote drawer open |
| `led_idle_on` | none | Start screensaver |
| `led_idle_off` | none | Stop screensaver |
| `led_off` | none | Strip dark |
| `led_idle_1` | none | Idle mode 1 |
| `led_idle_2` | none | Idle mode 2 |
| `led_blink` | `r`, `g`, `b`, `times` | Colored blink |
| `led_tail` | `r`, `g`, `b`, `cycles`, `delay_ms`  | Tail animation |
| `set_idle_screen` | `line1`, `line2`, `line3` | Change OLED idle text |
| `oled_show` | `line1`, `line2`, `line3`, `hold_ms` | Show temp message |

---

## Running the Dashboard

**On Raspberry Pi:**
```bash
cd nicegui
python dashboard.py
# Open http://10.201.48.7:8090
```

**On Windows (development):**
```powershell
cd nicegui
.\.venv\Scripts\Activate.ps1
python dashboard.py
# Open http://localhost:8090
```

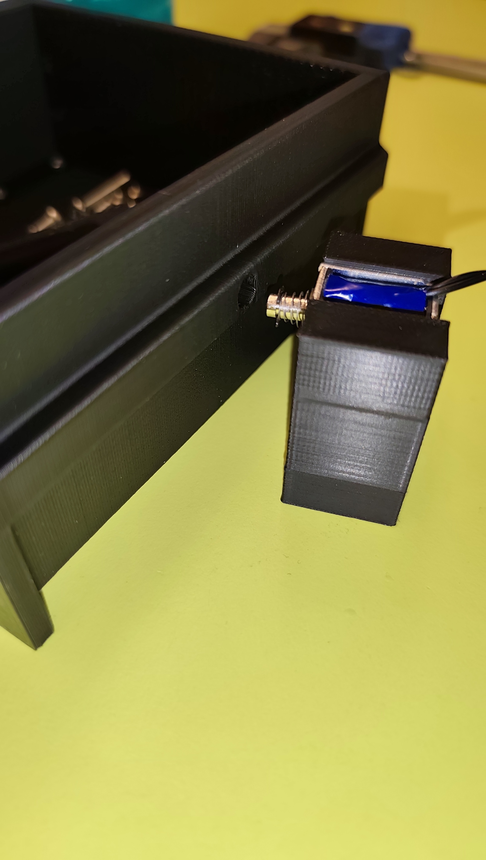
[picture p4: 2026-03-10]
solenoid_&_drawer.jpg

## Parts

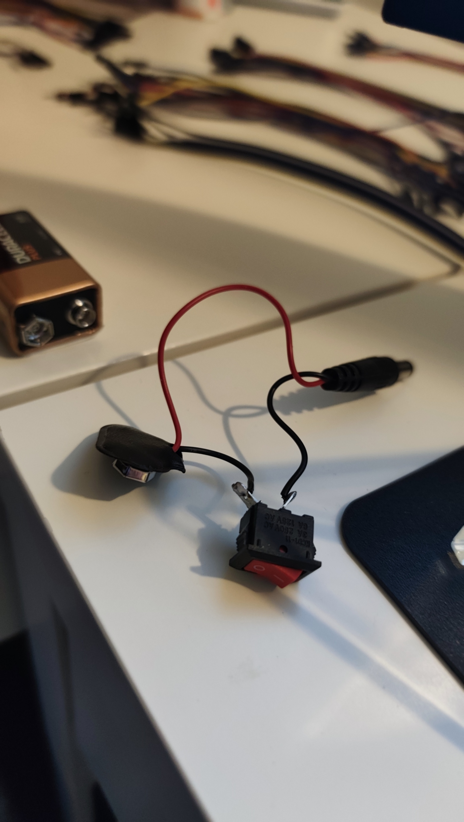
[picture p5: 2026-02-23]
Images/Parts_Of_Project/on_off_button_+_9v.png

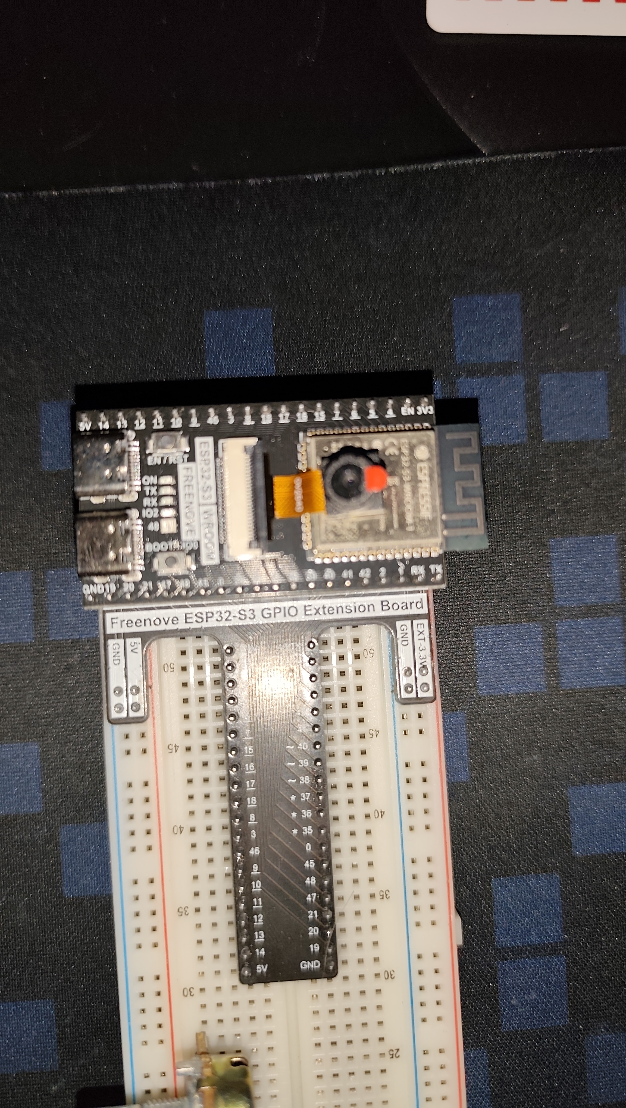
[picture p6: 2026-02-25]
Images/Parts_Of_Project/ESP32-S3 & Extension Board.jpg

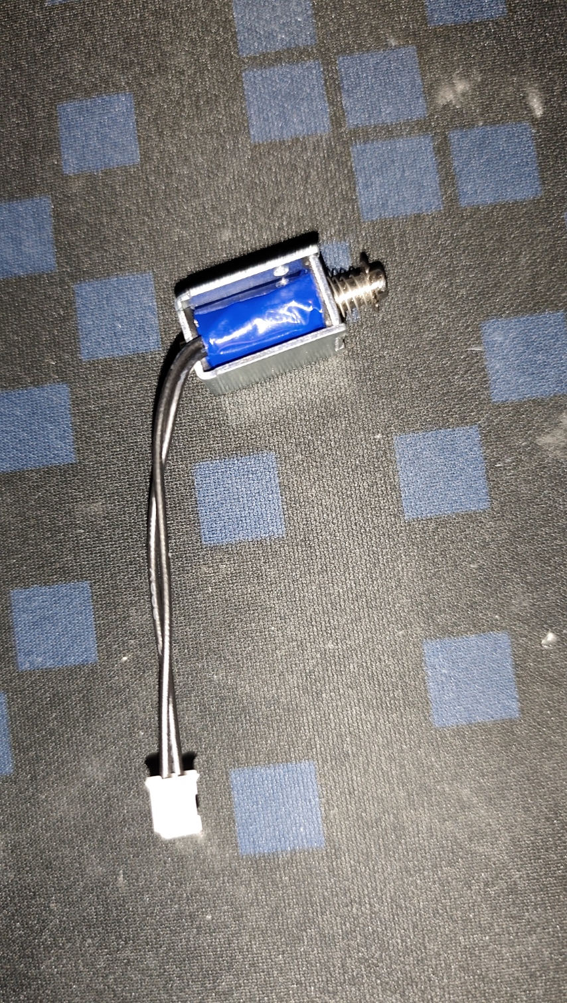
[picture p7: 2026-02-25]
Images/Parts_Of_Project/Part Solenoid 5v.jpg

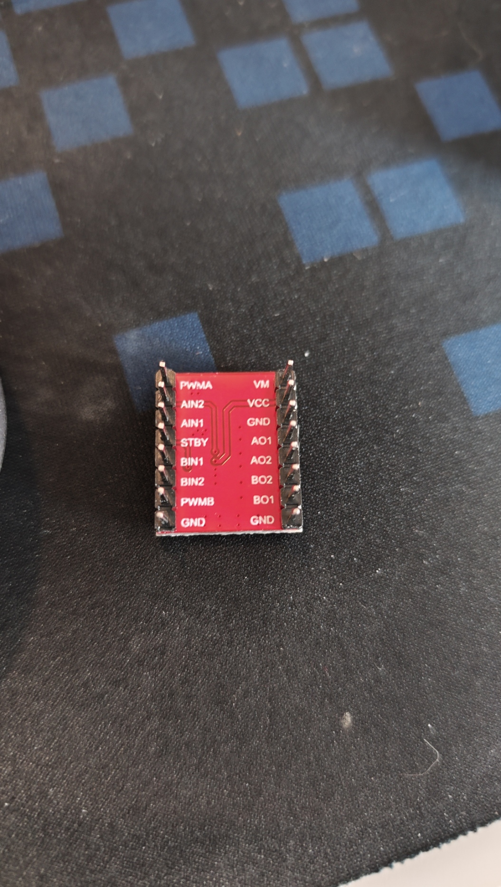
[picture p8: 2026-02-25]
Images/Parts_Of_Project/TB6612FNG.jpg

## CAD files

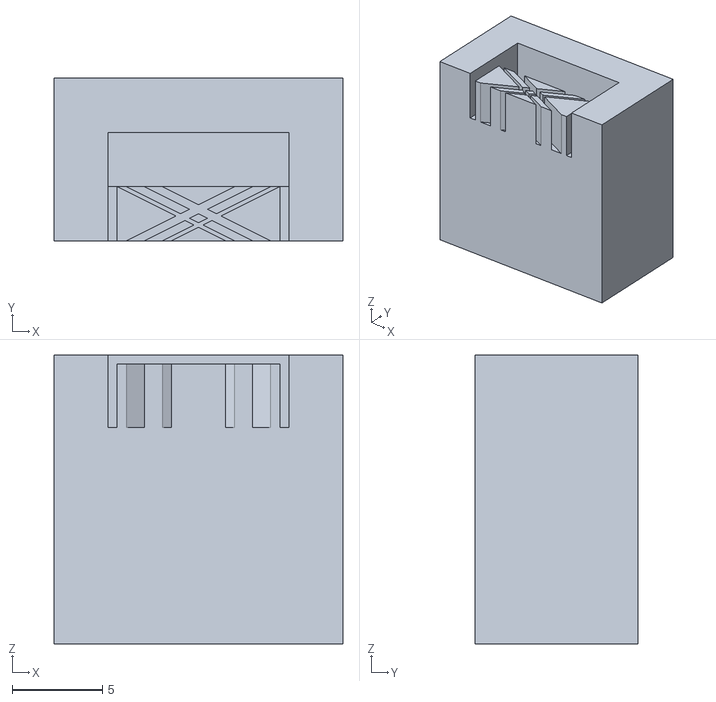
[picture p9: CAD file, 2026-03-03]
cad/MAIN SPRING HOLDER MODULE.stl
16.0 x 9.00 x 16.0

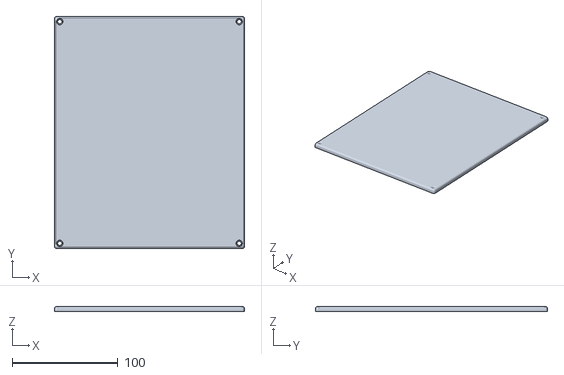
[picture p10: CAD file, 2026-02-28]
cad/MAIN LID ON BOX.stl
180.0 x 220.0 x 5.00

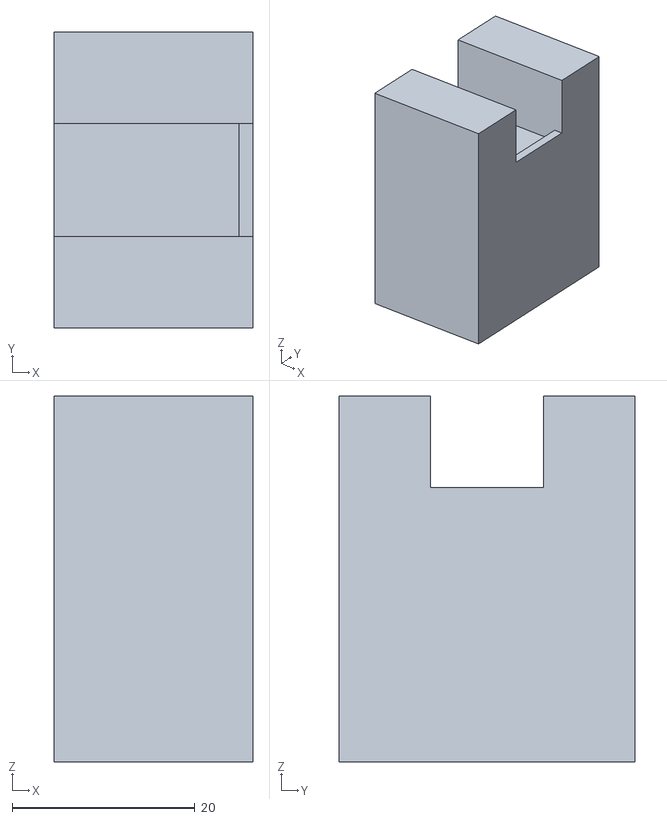
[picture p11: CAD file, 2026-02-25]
cad/MAIN SOLENOID MODULE.stl
21.7 x 32.3 x 40.0

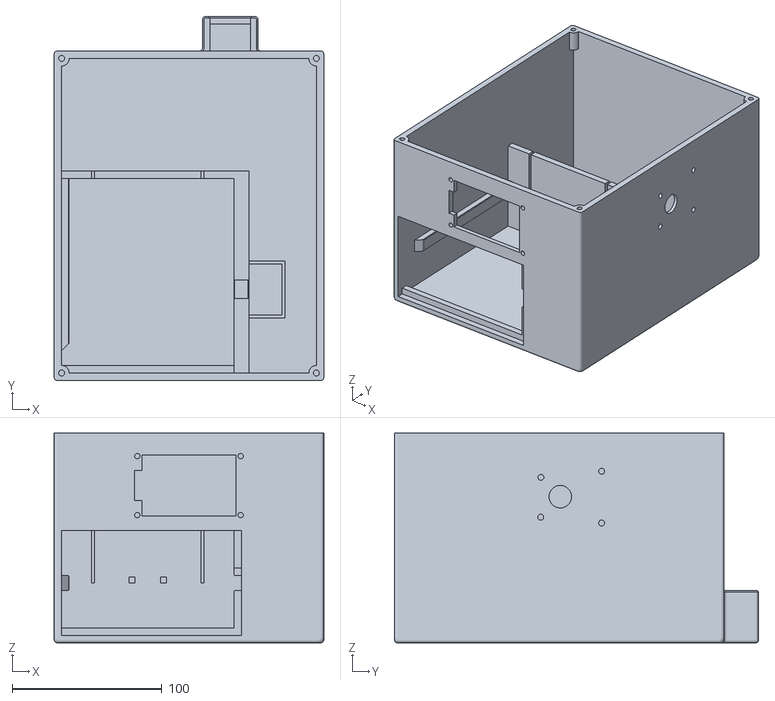
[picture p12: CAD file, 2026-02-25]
cad/MAIN BOX.stl
180.0 x 243.0 x 140.0

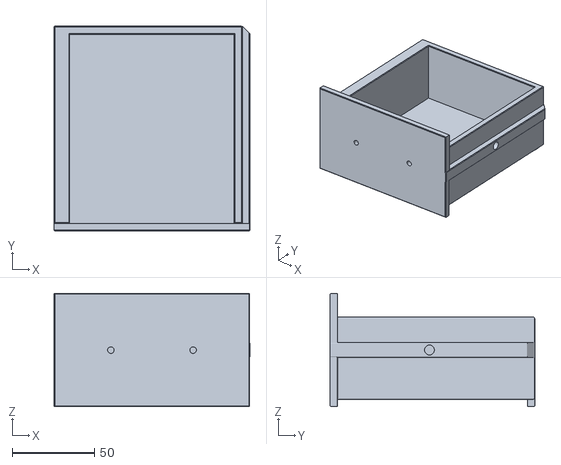
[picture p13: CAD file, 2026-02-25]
cad/MAIN DRAWER.stl
119.2 x 124.5 x 69.0

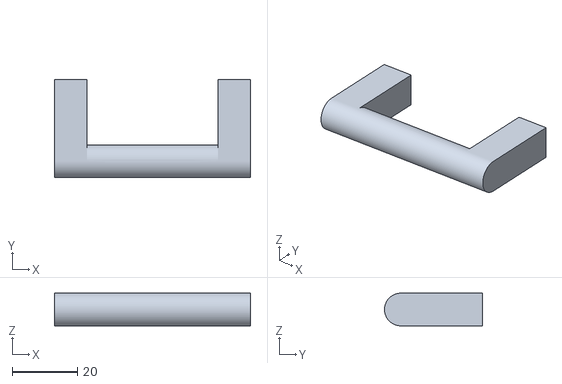
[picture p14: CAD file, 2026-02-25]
cad/MAIN HANDLE.stl
60.0 x 30.0 x 10.0

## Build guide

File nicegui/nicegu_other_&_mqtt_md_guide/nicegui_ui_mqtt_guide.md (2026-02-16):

# NiceGUI UI + MQTT publish logging (mini guide)

This guide covers:

- NiceGUI UI creation (expanded): containers, spacing, widths, backgrounds, and common patterns.
- MQTT `on_publish` logging: how to log publish confirmations into an on-page log window.

---

## 1) NiceGUI UI creation (expanded)

NiceGUI builds UI with Python context managers (`with ...:`). A “container” is just a component that holds other components.

### 1.1 Core container components

Most used:
- `ui.card()` boxed panel (group controls)
- `ui.row()` horizontal layout
- `ui.column()` vertical layout
- `ui.grid(columns=...)` grid layout
- `ui.separator()` divider line

Useful extras:
- `ui.scroll_area()` scrollable container (logs, long lists)
- `ui.expansion()` collapsible section (advanced controls)
- `ui.tabs()` + `ui.tab_panels()` multi-page UI on one route

### 1.2 Card + row + controls (baseline pattern)

```python
from nicegui import ui

@ui.page('/')
def index():
    with ui.card().classes('w-full p-4 border rounded'):
        ui.label('Skull Control').classes('text-lg font-bold')

        ui.separator()

        with ui.row().classes('gap-2'):
            ui.button('Eyes ON')
            ui.button('Eyes OFF')

        ui.separator()

        ui.label('Neck angle')
        ui.slider(min=0, max=180, value=90).props('label').classes('w-full')
```

### 1.3 Width control (why `w-50` didn’t work)

Tailwind has no `w-50` shorthand. Use one of these:
- `w-1/2` half width
- `w-full` full width
- `max-w-xl` (or `max-w-lg`, `max-w-2xl`) max width panel
- `w-[520px]` exact pixels

Centered “panel” pattern:

```python
with ui.row().classes('justify-center'):
    with ui.card().classes('w-full max-w-xl p-4 border rounded'):
        ui.label('Centered control panel')
```

### 1.4 Background colors (component-level)

Tailwind class:
```python
with ui.card().classes('w-full p-4 rounded bg-gray-100'):
    ui.label('Light background card')
```

Inline CSS:
```python
with ui.card().style('background-color: #0b1220; color: white;').classes('w-full p-4 rounded'):
    ui.label('Dark theme card')
```

### 1.5 Background color (whole page)

```python
ui.query('body').style('background-color: #0b1220; color: #e5e7eb;')
```

### 1.6 Spacing / alignment cheatsheet

- `p-4`, `p-2` padding
- `gap-2`, `gap-4` spacing inside rows/columns
- `mt-2`, `mb-2` margins
- `items-center` vertical align in a row
- `justify-center`, `justify-between` row alignment
- `rounded`, `border`, `border-gray-400`

### 1.7 Scalable “multiple cards” layout

```python
with ui.row().classes('justify-center w-full'):
    with ui.column().classes('w-full max-w-xl gap-4'):

        with ui.card().classes('p-4 border rounded'):
            ui.label('Eyes').classes('font-bold')

        with ui.card().classes('p-4 border rounded'):
            ui.label('Motors').classes('font-bold')

        with ui.card().classes('p-4 border rounded'):
            ui.label('Log').classes('font-bold')
```

### 1.8 More element commands (quick reference)

Text:
- `ui.label('text')`
- `ui.markdown('**bold**')`

Buttons:
- `ui.button('Title', on_click=handler)`
- `ui.button(...).props('color=negative')`

Inputs:
- `ui.input(label='Name')`
- `ui.number(label='Speed', value=10)`
- `ui.switch('Enabled')`
- `ui.checkbox('Option')`
- `ui.select(options=[...], value=...)`

Feedback:
- `ui.notify('Saved')`
- `ui.badge('Connected')`

Grouping:
- `ui.separator()`
- `ui.expansion('Advanced')`
- `ui.tabs()` / `ui.tab_panels()`

### 1.9 Reliable event pattern

Prefer reading values from the component itself:

```python
def on_changed():
    handler(component.value)

component.on('update:model-value', on_changed)
```

---

## 2) MQTT `on_publish` logging into your UI log

`on_publish` runs when the client finishes publishing.

- QoS 0: “sent/queued” (no broker ack required)
- QoS 1/2: confirms broker handshake

### 2.1 Minimal `on_publish` logger

```python
def on_publish(client, userdata, mid):
    log(f'Published mid={mid}')

client.on_publish = on_publish
```

### 2.2 Match publishes to payloads (queued -> published)

```python
PENDING: dict[int, dict] = {}

def send_command(payload: dict) -> None:
    ensure_mqtt_started()
    info = client.publish(TOPIC, json.dumps(payload).encode('utf-8'), qos=1)
    PENDING[info.mid] = payload
    log(f'Queued mid={info.mid}: {payload}')

def on_publish(client, userdata, mid):
    payload = PENDING.pop(mid, None)
    if payload is None:
        log(f'Published mid={mid}')
        return
    log(f'Published mid={mid}: {payload}')

client.on_publish = on_publish
```

### 2.3 When not to use `wait_for_publish()` in UI

`wait_for_publish()` blocks. Avoid it in slider callbacks. Use it only for one-off testing.

---

## 3) Compact “UI + MQTT logging” sample

```python
from nicegui import ui
import paho.mqtt.client as mqtt
import json
import time

BROKER = 'test.mosquitto.org'
PORT = 1883
TOPIC = '1404-remote-sender'

client = mqtt.Client()
mqtt_started = False

logs = []
PENDING = {}
log_box = None

def log(message):
    global log_box
    timestamp = time.strftime('%H:%M:%S')
    logs.append(f'[{timestamp}] {message}')
    if len(logs) > 50:
        logs.pop(0)
    if log_box is not None:
        log_box.set_value('\n'.join(logs))
    print(f'[{timestamp}] {message}')

def ensure_mqtt_started():
    global mqtt_started
    if mqtt_started:
        return
    client.connect(BROKER, PORT, keepalive=30)
    client.loop_start()
    mqtt_started = True
    log(f'MQTT connected to {BROKER}:{PORT}')

def on_publish(client, userdata, mid):
    payload = PENDING.pop(mid, None)
    if payload is None:
        log(f'Published mid={mid}')
        return
    log(f'Published mid={mid}: {payload}')

client.on_publish = on_publish

def send_command(payload):
    ensure_mqtt_started()
    info = client.publish(TOPIC, json.dumps(payload).encode('utf-8'), qos=1)
    PENDING[info.mid] = payload
    log(f'Queued mid={info.mid}: {payload}')

def eyes_on():
    send_command({'type': 'eyes', 'enabled': True})

def eyes_off():
    send_command({'type': 'eyes', 'enabled': False})

@ui.page('/')
def index():
    global log_box
    ensure_mqtt_started()

    ui.query('body').style('background-color: #0b1220; color: #e5e7eb;')

    with ui.row().classes('justify-center w-full'):
        with ui.card().classes('w-full max-w-xl p-4 border border-gray-500 rounded bg-white'):
            ui.label('Skull Remote').classes('text-lg font-bold')

            with ui.row().classes('gap-2'):
                ui.button('Eyes ON', on_click=eyes_on)
                ui.button('Eyes OFF', on_click=eyes_off)

            ui.separator()

            log_box = ui.textarea(value='', label='Log').props('readonly').classes(
                'w-full h-44 border border-gray-400 rounded'
            )

            log('UI loaded')

ui.run(host='127.0.0.1', port=8090, reload=False)
```

---

## 4) Practical next steps

1) Keep QoS 0 while iterating fast.
2) Switch critical commands to QoS 1 later (stop_all, scene start/stop).
3) Add `/ack` from ESP32 when you want real hardware confirmation.
4) Keep the UI log compact and visible; it saves hours of guessing.

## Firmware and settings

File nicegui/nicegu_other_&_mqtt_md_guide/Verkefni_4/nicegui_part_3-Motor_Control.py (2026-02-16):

"""
nicegui_part_3-Motor_Control.py

Part 3 of V4.md - Control ESP32 motors from NiceGUI
- Two text inputs + button to send motor angles
- Joystick control for motors
- Display current motor status

"""

# -----------------------------
# Default imports for this part
# -----------------------------
import os
import sys
import json
from datetime import datetime
import asyncio
from aiomqtt import Client
from nicegui import ui

# -----------------------------
# NiceGUI server config
# -----------------------------

NICEGUI_HOST = os.getenv("NICEGUI_HOST", "127.0.0.1")
NICEGUI_PORT = int(os.getenv("NICEGUI_PORT", "8090"))

# -----------------------------
# MQTT config
# -----------------------------

# MQTT_BROKER = "test.mosquitto.org"
MQTT_BROKER = "broker.emqx.io"
MQTT_TOPIC_MOTORS = "1404TOPIC_MOTORS"

# -----------------------------
# Servo limits (matching ESP32)
# -----------------------------

NECK_MIN = 0
NECK_MAX = 180
NECK_START = 90

MOUTH_MIN = 10
MOUTH_MAX = 50
MOUTH_START = 10

# -----------------------------
# App state
# -----------------------------

MAX_LOG_LINES = 50
log_lines = []

# Motor angles for input binding
motor_input = {
    "neck": NECK_START,
    "mouth": MOUTH_START,
}

# Joystick axis enable/disable
joystick_settings = {
    "neck_enabled": True,
    "mouth_enabled": False,
}

# UI references for status display
neck_status_label = None
mouth_status_label = None


# -----------------------------
# Logger utility
# -----------------------------
def add_log(message):
    timestamp = datetime.now().strftime("%H:%M:%S")
    log_lines.append(f"{timestamp} - {message}")
    del log_lines[:-MAX_LOG_LINES]
    render_log_box.refresh()


def clear_log():
    log_lines.clear()
    render_log_box.refresh()


@ui.refreshable
def render_log_box():
    if not log_lines:
        ui.label("Log is empty").classes("text-xs opacity-70")
        return

    for line in reversed(log_lines):
        ui.label(line).classes("text-xs")


# -----------------------------
# Update status labels
# -----------------------------
def update_status_display(neck_angle, mouth_angle):
    if neck_status_label:
        neck_status_label.set_text(f"{neck_angle}°")
    if mouth_status_label:
        mouth_status_label.set_text(f"{mouth_angle}°")


# -----------------------------
# Send motor command via MQTT
# -----------------------------
async def send_motor_command(neck_angle, mouth_angle):
    # Clamp to limits
    neck_angle = max(NECK_MIN, min(NECK_MAX, int(neck_angle)))
    mouth_angle = max(MOUTH_MIN, min(MOUTH_MAX, int(mouth_angle)))

    # Update input state
    motor_input["neck"] = neck_angle
    motor_input["mouth"] = mouth_angle

    # Create payload
    payload = {
        "motor1": neck_angle,
        "motor2": mouth_angle,
    }

    # Send via MQTT
    try:
        async with Client(MQTT_BROKER) as client:
            await client.publish(MQTT_TOPIC_MOTORS, json.dumps(payload).encode())
            add_log(f"Sent: Neck={neck_angle}°, Mouth={mouth_angle}°")
    except Exception as error:
        add_log(f"MQTT Error: {error}")

    # Update display
    update_status_display(neck_angle, mouth_angle)


# -----------------------------
# Button click handler
# -----------------------------
def send_button_clicked():
    neck_angle = int(motor_input["neck"])
    mouth_angle = int(motor_input["mouth"])
    asyncio.create_task(send_motor_command(neck_angle, mouth_angle))


# -----------------------------
# Joystick handlers
# -----------------------------
def joystick_moved(event):
    neck_angle = motor_input["neck"]
    mouth_angle = motor_input["mouth"]

    if joystick_settings["neck_enabled"]:
        neck_center = (NECK_MIN + NECK_MAX) // 2
        neck_range = (NECK_MAX - NECK_MIN) // 2
        neck_angle = int(neck_center + (event.x * neck_range))

    if joystick_settings["mouth_enabled"]:
        mouth_center = (MOUTH_MIN + MOUTH_MAX) // 2
        mouth_range = (MOUTH_MAX - MOUTH_MIN) // 2
        mouth_angle = int(mouth_center + (event.y * mouth_range))

    asyncio.create_task(send_motor_command(neck_angle, mouth_angle))


def joystick_released(_):
    if joystick_settings["neck_enabled"]:
        neck_angle = NECK_START
    else:
        neck_angle = motor_input["neck"]

    if joystick_settings["mouth_enabled"]:
        mouth_angle = MOUTH_START
    else:
        mouth_angle = motor_input["mouth"]

    asyncio.create_task(send_motor_command(neck_angle, mouth_angle))


# -----------------------------
# Main page
# -----------------------------
@ui.page("/")
def index():
    global neck_status_label, mouth_status_label

    with ui.card().classes("max-w-7xl w-full mx-auto p-6 space-y-4"):

        ui.label("NiceGUI - Part 3: Motor Control").classes("text-lg font-bold")
        ui.label("Control ESP32 servos via MQTT").classes("text-sm opacity-70")

        # -----------------------------
        # Motor status card
        # -----------------------------
        with ui.card().classes("w-full"):
            ui.label("Servo Status").classes("text-md font-semibold")

            with ui.row().classes("w-full justify-around"):
                with ui.column().classes("items-center"):
                    ui.label("Neck").classes("text-sm")
                    ui.label(f"{NECK_MIN}° - {NECK_MAX}°").classes("text-xs opacity-70")
                    neck_status_label = ui.label(f"{NECK_START}°").classes(
                        "text-4xl font-bold text-green-500"
                    )

                with ui.column().classes("items-center"):
                    ui.label("Mouth").classes("text-sm")
                    ui.label(f"{MOUTH_MIN}° - {MOUTH_MAX}°").classes(
                        "text-xs opacity-70"
                    )
                    mouth_status_label = ui.label(f"{MOUTH_START}°").classes(
                        "text-4xl font-bold text-purple-500"
                    )

        # -----------------------------
        # Method 1: Manual input
        # -----------------------------
        with ui.card().classes("w-full"):
            ui.label("Method 1: Manual Input").classes("text-md font-semibold")

            with ui.row().classes("w-full items-end gap-4"):
                ui.number(
                    label=f"Neck ({NECK_MIN}-{NECK_MAX})",
                    min=NECK_MIN,
                    max=NECK_MAX,
                ).bind_value(motor_input, "neck").classes("w-48").on(
                    "keydown.enter", send_button_clicked
                )

                ui.number(
                    label=f"Mouth ({MOUTH_MIN}-{MOUTH_MAX})",
                    min=MOUTH_MIN,
                    max=MOUTH_MAX,
                ).bind_value(motor_input, "mouth").classes("w-48").on(
                    "keydown.enter", send_button_clicked
                )

                ui.button("Send", on_click=send_button_clicked).classes("bg-blue-500")
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

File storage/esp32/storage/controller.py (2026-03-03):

# ==========================================
# file: controller.py
# ==========================================
# Purpose:
# - Hold shared system state + shared utilities.
# - Provide ONE log() function:
#   - prints to console
#   - shows on OLED (non-blocking)
#   - optionally publishes JSON to the dashboard (MQTT)
#
# OLED rule:
# - No timers in log().
# - log() only shows the requested message.
# - Procedures decide exactly when to return to main mode.
# ==========================================

import uasyncio as asyncio
import time


class SecurityBoxController:
    def __init__(self, oled, led_strip, solenoid, reed, rfid):
        # Hardware references
        self.oled = oled
        self.led_strip = led_strip
        self.solenoid = solenoid
        self.reed = reed
        self.rfid = rfid

        # MQTT broker reference (injected)
        self.broker = None

        # Unlock guard
        self.unlock_in_progress = False

        # System lock (silent ignore) for procedures that must be exclusive
        self.system_locked = False

    # --------------------------------------------------
    # Exclusive lock helpers (silent ignore behavior)
    # --------------------------------------------------
    def lock_system_now_utility(self):
        self.system_locked = True

    def unlock_system_now_utility(self):
        self.system_locked = False

    # --------------------------------------------------
    # Wiring: inject broker so controller can publish events
    # --------------------------------------------------
    def set_broker(self, broker):
        self.broker = broker

    # --------------------------------------------------
    # Timestamp helper
    # --------------------------------------------------
    def time_utility(self):
        try:
            year, month, day, hour, minute, second, _, _ = time.localtime()
            return "{:04d}-{:02d}-{:02d} {:02d}:{:02d}:{:02d}".format(
                year, month, day, hour, minute, second
            )
        except Exception:
            return ""

    # --------------------------------------------------
    # Unified logger (no timers, no auto-revert)
    # --------------------------------------------------
    def log(
        self,
        line1,
        line2="",
        line3="",
        publish_event=None,
        publish_source=None,
        publish_data=None,
        publish_success=True,
    ):
        # Console output is always useful for debugging
        print(line1, line2, line3)

        # OLED output is fire-and-forget, because procedures should block when needed
        if self.oled is not None:
            asyncio.create_task(
                self.oled.show_three_lines_async(
                    str(line1),
                    str(line2),
                    str(line3),
                )
            )

        # Optional JSON publish
        if publish_event and self.broker is not None:
            payload = {
                "event": publish_event,
                "source": publish_source or "esp32",
                "status": "ok" if publish_success else "fail",
                "timestamp": self.time_utility(),
            }

            if publish_data is not None:
                payload["data"] = publish_data

            self.broker.send_json(payload)

    # --------------------------------------------------
    # RFID callbacks
    # --------------------------------------------------
    async def rfid_allowed_async(self, uid_hex, card_label, unlock_procedure_async):
        # Silent ignore while locked or already unlocking
        if self.system_locked or self.unlock_in_progress:
            return

        # Start unlock flow
        await unlock_procedure_async(source="rfid", uid_hex=uid_hex, label=card_label)

    async def rfid_denied_async(self, uid_hex):
        # Silent ignore while locked
        if self.system_locked:
            return

        uid_suffix = uid_hex[-6:] if uid_hex else ""

        self.log(
            "RFID",
            "DENIED",
            uid_suffix,
            publish_event="rfid_denied",
            publish_source="rfid",
            publish_data={"uid_suffix": uid_suffix},
            publish_success=False,
        )

        if self.led_strip:
            asyncio.create_task(self.led_strip.blink_red_three_times_async())

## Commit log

2026-02-23 flow chart
2026-02-25 STL files in /cad
    [MAIN BOX.stl, MAIN DRAWER.stl, MAIN HANDLE.stl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]
2026-02-26 changed class files, added class file for each part, started on tasks.py which will be imported into the main.py file and the tasks will hold all tasks merging... main.py will handle sending and rece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
    [led_class.py, oled_screen.py, oled_screen_class.py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]
2026-02-26 26 feb documentation because of solenoid not having the power it needs to unlock when pressed on
2026-02-28 main lid on box stl file
    [MAIN LID ON BOX.stl]
2026-03-01 Added: Flow chart png. Edited: Special images folder and folder inside it with picture of ALL parts used in this project (except for the structure of course)
2026-03-01 Complete ESP32 security box rewrite + NiceGUI dashboard
    ESP32 side:
    - main.py: boot orchestrator (was empty)
    - mqtt_broker.py: new two-task MQTT manager (rx_task + tx_task) using
    umqtt.simple poll loop; list-based FIFO queue; primary/fallback brokers
    - tasks.py: full rewrite as SecurityBoxController class with async state
    machine, RFID seq-number event dispatch, whitelisted MQTT call pattern,
    and cancellable LED animation tasks
    - classes/led_strip_class.py: new 50-LED GRB strip class; fixes animation
    hiccup by yielding with await asyncio.sleep_ms() at every frame
    - classes/oled_screen_class.py: added async wrappers (show_status_async,
    show_three_lines_async, clear_async), mark_acti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
    [led_strip_class.py, mqtt_broker.py, oled_screen_class.py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]
2026-03-03 updated esp32 class files and main files and nicegui dashboard setup in 3 files for the box
2026-03-03 small evening changes
    [MAIN SPRING HOLDER MODULE.stl]
2026-03-05 Implement idle loop for LED strip and update OLED screen methods; enhance MQTT broker for offline mode
    [led_strip.py, oled_screen.py]
2026-03-10 complete code finally! Fully upgraded system that also works with no broker and no internet and can still scan cards, keychain or even phone and is fully working.
    [led_strip.py]
